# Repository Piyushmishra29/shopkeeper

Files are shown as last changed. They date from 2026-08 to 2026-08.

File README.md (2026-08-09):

<p align="center">
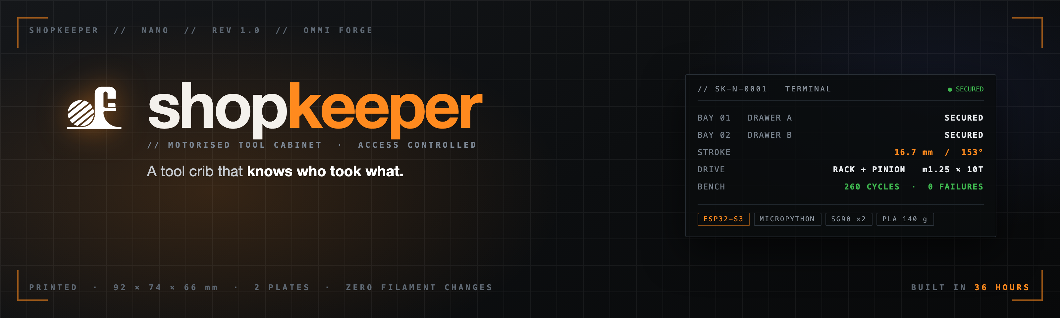
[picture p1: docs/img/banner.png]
shopkeeper NANO — a motorised tool cabinet
  
</p>

<p align="center">
  
  
  
  
</p>

<p align="center">
  
  
  
  
</p>

**A tool crib that knows who took what.**

Type a PIN on your phone and the one drawer you are cleared for slides itself open. Take what you
need, push it shut, and the pick is logged against your name. Try the other drawer and nothing
moves.

Built as a working demonstrator to pitch against the industrial smart tool cabinets that land in
India around **₹20 lakh**. Same job, out of about 140 g of filament and roughly ₹2,000 of parts.

<p align="center">
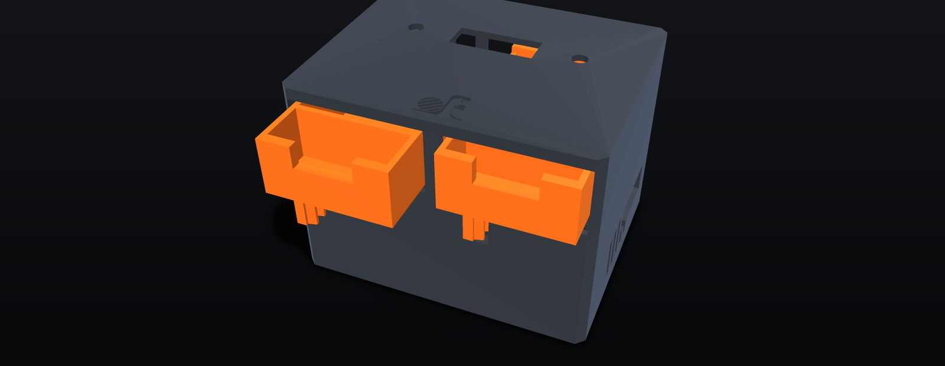
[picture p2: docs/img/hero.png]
shopkeeper NANO, one drawer driven open
  
</p>

<table>
<tr>
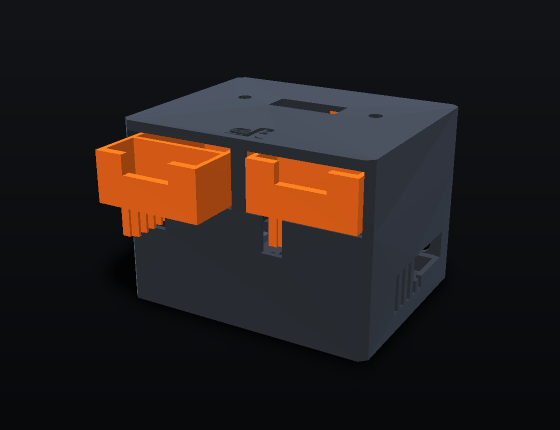
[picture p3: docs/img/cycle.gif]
a drawer opening and closing
<td width="50%"></td>
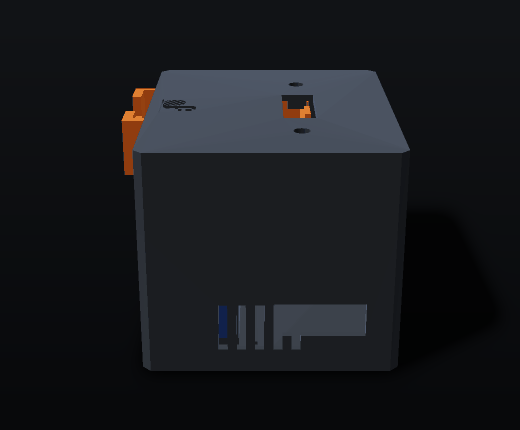
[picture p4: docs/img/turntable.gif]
turntable
<td width="50%"></td>
</tr>
<tr>
<td align="center"><em>16.69 mm of travel, commanded</em></td>
<td align="center"><em>92 × 74 × 66 mm, 140 g of filament</em></td>
</tr>
</table>

> Every image and animation in this README is rendered from the shipped meshes by
> [`tools/make_assets.py`](tools/make_assets.py), through a numpy software rasteriser
> ([`tools/render.py`](tools/render.py)) written for the job because there is no GPU here. The
> mechanism animation turns the pinion by θ and slides the drawer by `R_P·θ` — the same relation
> the firmware commands. Nothing is drawn by hand, so if the geometry is wrong the picture is wrong.

| | |
|---|---|
| **Machine** | shopkeeper **NANO**, 92 × 74 × 66 mm |
| **Geometry** | frozen — `nano/*.stl` is what goes on the plate |
| **Firmware** | 1.0.0, running on the board |
| **Print** | 2 plates, 140 g solid (~119 g sliced) |
| **Bench** | 60/60 open-close cycles on bay two, no failures, no brownout |
| **Spec** | [`docs/superpowers/specs/2026-08-08-toolcell-design.md`](docs/superpowers/specs/2026-08-08-toolcell-design.md) |
| **Lineage** | [`docs/history.md`](docs/history.md) — four superseded generations and what killed each |

---

## Why it exists

A machine shop bleeds tooling. Not dramatically — a carbide end mill walks off, nobody
remembers who had it last, and the shop buys another. Nobody is stealing; nobody is keeping
a record either. Multiply by a year and it is a real number, and it never appears on any
report because there is nothing generating one.

The fix is not measurement. You do not need to weigh, photograph or tag anything to change
behaviour — you need a drawer that stays shut until somebody is cleared to open it, and a
line in a log with their name on it. **Nobody walks off with a tool their name is attached
to.** The deterrent is the record.

So this is exactly that, and nothing beyond it: controlled access plus an append-only log,
on top of a tool database. **It counts nothing, and the interface says so** rather than
implying a measurement it never takes. There is no load cell, no camera, no RFID, and the
page does not pretend otherwise.

Built in 36 hours out of 140 g of filament and about ₹2,000 of parts, so the argument can be
made with a working machine on the table instead of a slide.

---

---

## The machine that exists

<p align="center">
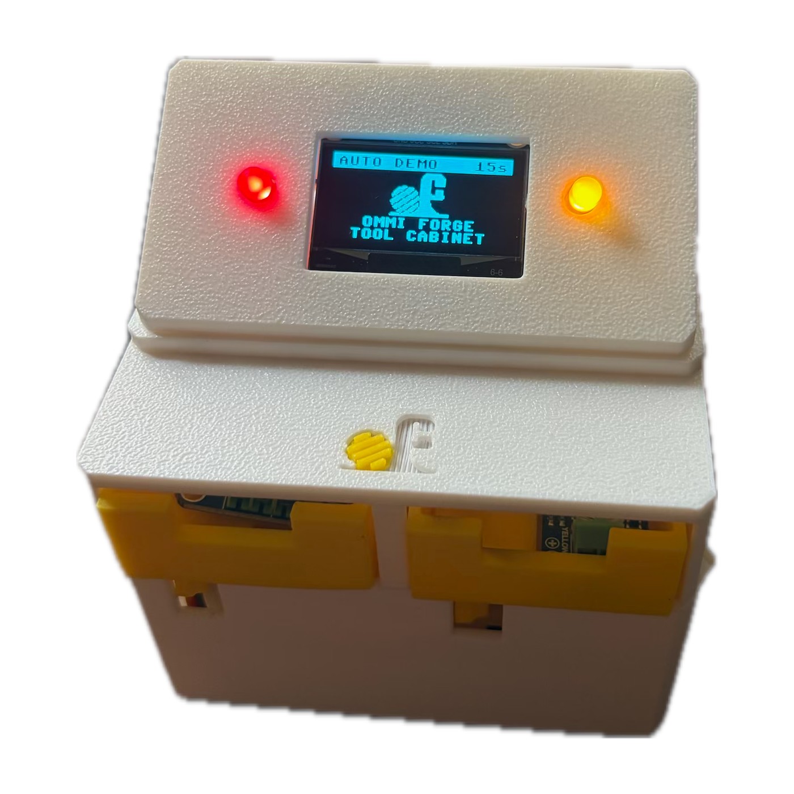
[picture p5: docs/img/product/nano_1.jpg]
shopkeeper NANO, assembled and running
  
</p>

<table>
<tr>
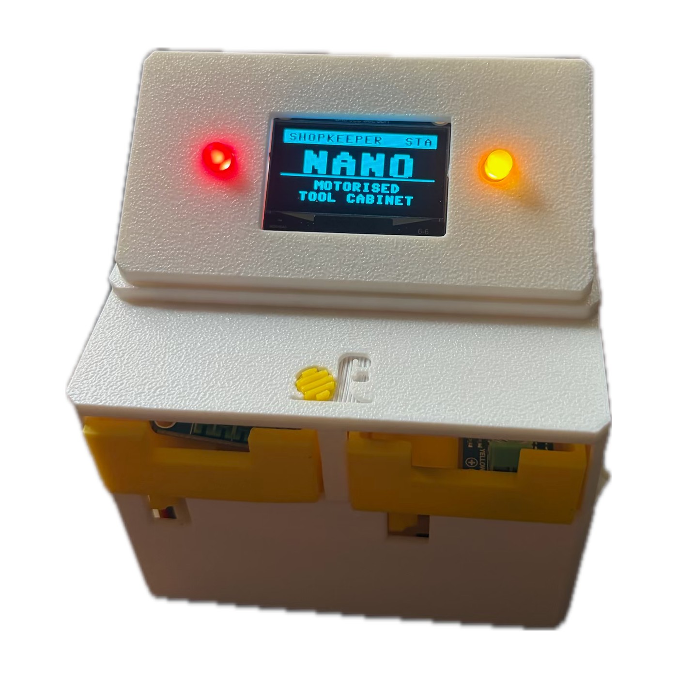
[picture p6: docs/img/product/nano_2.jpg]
shopkeeper NANO
<td width="33%"></td>
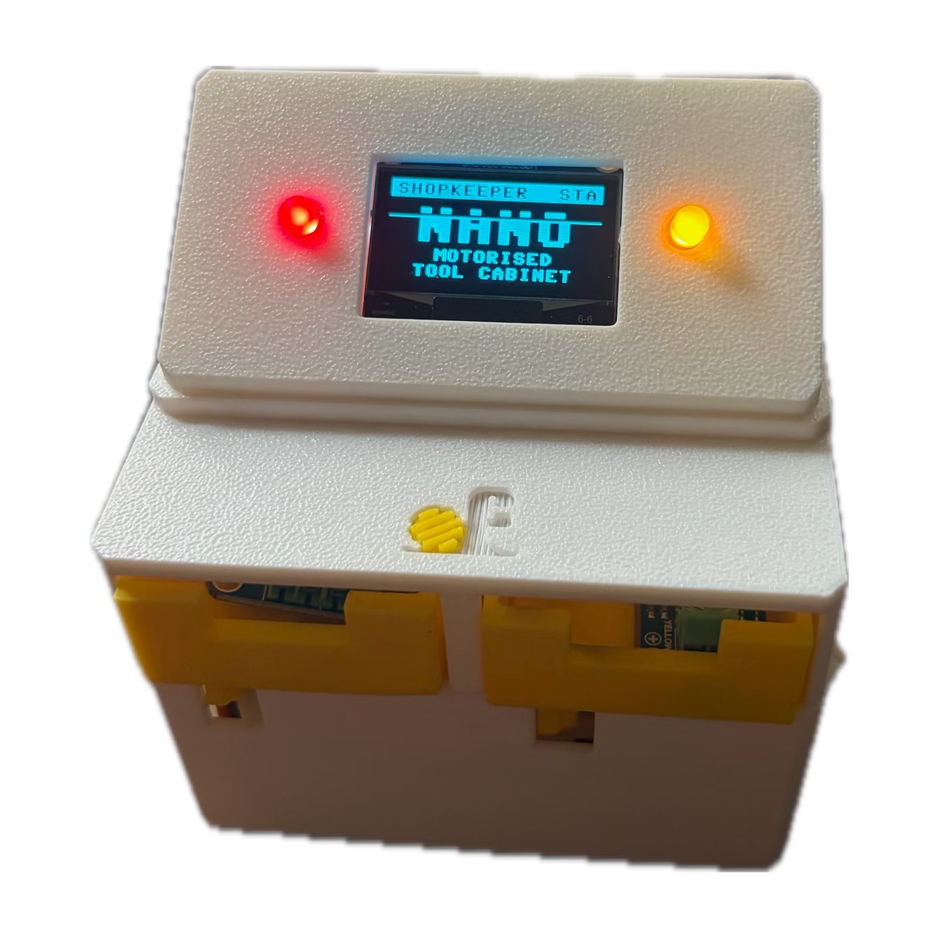
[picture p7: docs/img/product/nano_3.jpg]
shopkeeper NANO
<td width="33%"></td>
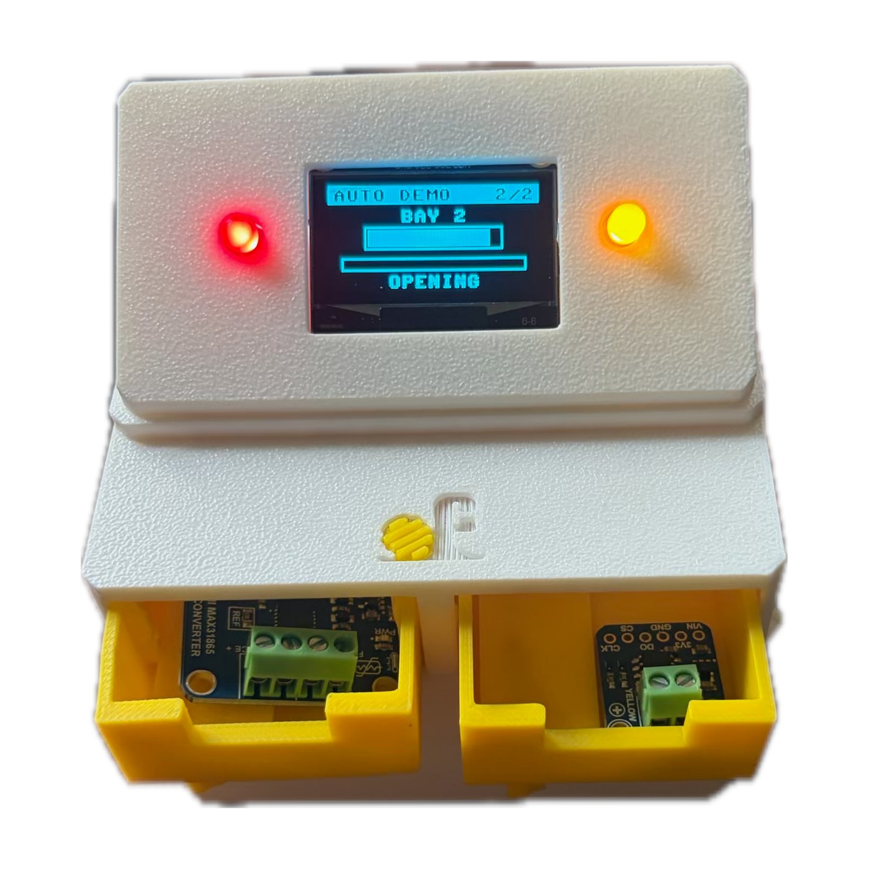
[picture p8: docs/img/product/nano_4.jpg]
shopkeeper NANO
<td width="33%"></td>
</tr>
</table>

Not a render — the printed article, powered up, mid attract-loop. The panel is
showing the scripted demo counting down; the two lamps are the bay indicators;
the mark on the lid is a separate part pressed into a debossed pocket, printed
in the same 0.4 nozzle as everything else.

Everything on this page is measured from that object or from the meshes that
produced it. **260 open-close cycles, zero failures**, both bays driven
simultaneously.

Photographs were cut from their background with `tools/cutout.swift`, which
uses Vision's foreground-instance mask — the same engine behind Preview's
Remove Background. The obvious route was `rembg`, which cannot be installed
here: `onnxruntime` has no build for Python 3.14.

---

---

## Bench results

| run | result |
|---|---|
| bay 2, sequential | 60 / 60 |
| bay 1, **concurrent** | 100 / 100 |
| bay 2, **concurrent** | 100 / 100 |
| **total** | **260 cycles · 0 failures · 0 reboots** |

The last two runs drove **both bays at once** — two servos under load on one rail, which is the
worst case for supply sag. Nothing reset.

A cycle only counts if the harness polled until the drawer stopped moving **and** its own open
flag had flipped. The API returns `202` on acceptance, so counting requests would have proved
nothing. Harness and raw reports: [`tools/bay2_endurance.py`](tools/bay2_endurance.py).

## How it works

```mermaid
flowchart LR
  P["Phone or laptop<br/>any browser"] -->|"HTTP · PIN"| E
  subgraph CAB["shopkeeper NANO"]
    E["ESP32-S3<br/>MicroPython 1.28"]
    E -->|"PWM 650–2350 µs"| S1["SG90 · GPIO 5"]
    E -->|"PWM 650–2350 µs"| S2["SG90 · GPIO 6"]
    E -->|"I²C · GPIO 1/2"| D["SH1106 OLED<br/>top face"]
    E -->|"append-only"| L[("Log<br/>/data on flash")]
    S1 --> R1["pinion m1.25 × 10T"] --> B1["Bay 1 drawer<br/>16.7 mm"]
    S2 --> R2["pinion m1.25 × 10T"] --> B2["Bay 2 drawer<br/>16.7 mm"]
  end
```

Everything is on the board. No cloud, no broker, no account — the cabinet raises its own
access point, so it works in a meeting room with no wifi and keeps working when the internet
does not.

The log is written **before** the confirmation goes back, so a move that happened is always
recorded even if the network drops mid-reply. The record is the product; it does not get to be
best-effort.

Sequence and state diagrams are in [`docs/BUILD.md`](docs/BUILD.md).

## Geometry for a client or a machine shop

Every part, in three formats. **The mesh is the same object in all of them** — one generator,
one export.

### → [**`MODELS/`**](MODELS/) ← everything is in here

| folder | format | for |
|---|---|---|
| [**`MODELS/STL/`**](MODELS/STL) | STL | printing, and 3D CAM — **start here** |
| [`MODELS/OBJ/`](MODELS/OBJ) | OBJ | import into almost anything |
| [`MODELS/PLATES-3MF/`](MODELS/PLATES-3MF) | 3MF | slicer-ready plates, orientation baked in |
| [`MODELS/DXF/`](MODELS/DXF) | DXF, mm | flat profiles for laser, waterjet or 2D cut |

[`MODELS/README.md`](MODELS/README.md) lists every part with its size and what it does.

<p align="center">
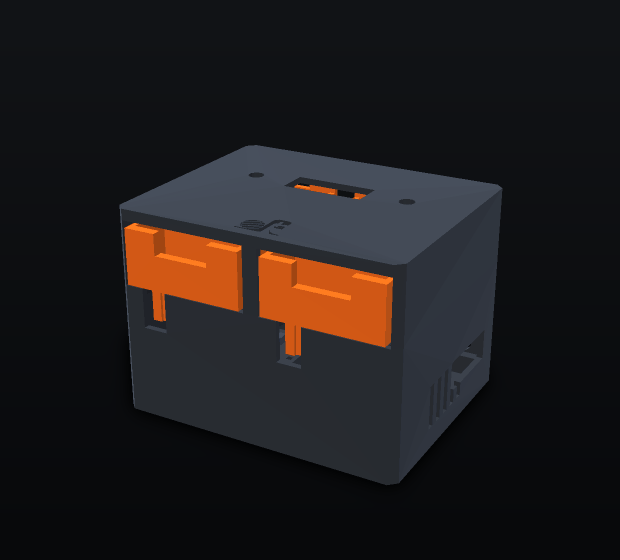
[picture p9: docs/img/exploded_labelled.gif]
exploded, each part named
  
</p>

**There is no STEP file, and it is worth saying why.** STEP is a boundary representation —
exact surfaces, true arcs, named faces. This geometry is a triangle mesh, authored for a
printer. Converting mesh to STEP does not recover what was never in it: you get a solid built
from thousands of facets, which imports and looks correct and is unpleasant to machine, because
every cylinder is really a polygon and the toolpath chatters around it.

If the shop wants proper B-rep, the honest route is to rebuild from `cad/nano.py` — every
dimension is a named entry in the `P` dict at the top of that file, and each part function
reads as a recipe. It is half a day for a CAD operator and the result is genuinely machinable.
Importing the STL into Fusion or FreeCAD and converting to solid is the fast, faceted
alternative and is fine for a one-off.

Regenerate the exports at any time:

```sh
.venv/bin/python cad/export_cam.py     # rebuilds MODELS/ entirely
```

---

---

## Scaling it

Two drawers is the demonstrator. Nothing about the approach is limited to two, and the reason
is the same rule that makes it secure: **only one drawer is ever open.** That single constraint
is what keeps a hundred-drawer wall cheap to power and simple to reason about.

| | drawers | actuation | power | what changes |
|---|---|---|---|---|
| **demonstrator** | 2 | 2 × SG90 direct from the board | USB power bank | — |
| **one cabinet** | 16 | 1 × PCA9685, 16 channels over I²C | 5 V 3 A | one driver board, same firmware loop |
| **a bay of cabinets** | 100+ | 7 × PCA9685 on one I²C bus | 5 V 5 A | addressing, not architecture |
| **a shop** | 32 cabinets | one controller each | local | a server that aggregates the logs |

### Why the power does not scale with the drawers

An SG90 pulls about 700 mA while it moves and nothing at all when it is detached — the firmware
already cuts the signal once a move settles. Because access control means **one drawer at a
time**, the worst case is one servo moving plus a hundred sitting idle, not a hundred moving.
A hundred-drawer wall draws about what this two-drawer box does.

That is not a lucky coincidence. The security model and the power budget are the same
constraint viewed twice.

### What actually gets harder

The mechanism scales by repetition. The hard parts are elsewhere, and they are all software:

- **Identity.** A 4-digit PIN does not survive fifty operators. It becomes an RFID badge or a
  phone, and the log has to carry a person rather than a session.
- **The database.** One cabinet can keep its log in flash. Thirty-two cabinets need a server,
  and the cabinets need to keep working when it is unreachable — local log, sync on reconnect.
- **Integration.** A shop wants tool consumption against a job number and a cost centre, which
  means talking to whatever ERP already exists.
- **Actuation, for real drawers.** An SG90 moves a 20 g printed bin. A drawer rated for 80 kg
  of tooling wants a proper geared motor or a solenoid latch and a gas strut. The rack and
  pinion stays; the motor changes.

**None of that is a hardware problem, and that is the point.** The cabinet is the cheap half.
What a shop is buying is controlled access and a record — and that is where both the difficulty
and the value sit.

---

## What it deliberately isn't

**It does not count anything.** Stock decrements because the software said you would take two.
Worth repeating, because it is the crux of the pitch rather than an apology: the ₹20 lakh cabinets
work the same way. Their inventory is trust-based, with no sensors anywhere in the product. The moat is access
control and the database, not sen## Geometry

### → [**`MODELS/`**](MODELS/) ←

| folder | for |
|---|---|
| [**`MODELS/STL/`**](MODELS/STL) | printing and 3D CAM — **start here** |
| [`MODELS/OBJ/`](MODELS/OBJ) | import into almost anything |
| [`MODELS/PLATES-3MF/`](MODELS/PLATES-3MF) | slicer-ready plates, orientation set |
| [`MODELS/DXF/`](MODELS/DXF) | flat profiles, mm, for laser or waterjet |

<p align="center">
  exploded, each part named
</p>

No STEP: this is a triangle mesh authored for a printer, and converting mesh to B-rep does not
recover surfaces that were never there. For real B-rep, rebuild from the `P` dict in
[`cad/nano.py`](cad/nano.py) — every dimension is one named number.
[`MODELS/README.md`](MODELS/README.md) lists every part and its size.

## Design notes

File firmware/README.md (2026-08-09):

# shopkeeper NANO — firmware

MicroPython for the ESP32-S3. Brings up its own wifi, serves a control UI, and
drives the two drawer servos.

Tested on the board in hand: **ESP32-S3, MicroPython 1.28.0**, 2.0 MB free heap.

## What it does, and why that

The industrial smart tool cabinets this is pitched against — the ~₹20 lakh ones — do
not sense anything. No load cells, no cameras, no RFID. Inventory is
trust-based. What a machine shop is actually buying is **a locked drawer and a
record of who opened it**, so that is exactly what this implements:

- a PIN gate that re-locks itself after two minutes idle
- every open, close, unlock and rejected PIN written to an append-only log
- a per-drawer tool register

Nothing here claims to know whether a tool is physically present, and the UI
says so rather than implying a measurement it never takes.

## Layout

```
config.py   everything a unit differs on: wifi, pins, PIN, endpoints, tools
servo.py    SG90 driver — eased moves, calibrated endpoints, auto-detach
store.py    calibration + log persistence, with flash-wear rate limiting
server.py   asyncio HTTP server and the JSON API
main.py     boot: network, restore calibration, park closed, serve
www/        the UI, served straight off flash
```

## Flashing

```sh
PORT=/dev/cu.usbmodem5A790574951          # yours may differ; ls /dev/cu.*
mpremote connect $PORT mkdir :www
for f in config.py servo.py store.py server.py main.py; do
  mpremote connect $PORT cp $f :$f
done
mpremote connect $PORT cp www/index.html :www/index.html
mpremote connect $PORT reset
```

`main.py` runs automatically on power-up. To watch it boot:
`mpremote connect $PORT repl` then Ctrl-D.

## Using it

The cabinet brings up its own access point, because a demonstrator has to work
in a meeting room with no guest wifi:

| | |
|---|---|
| SSID | `shopkeeper-NANO` |
| Password | `forge2026` |
| URL | **http://192.168.4.1/** |
| PIN | `2468` |

Set `JOIN = ("ssid", "password")` in `config.py` to join an existing network
first and fall back to the AP.

## Wiring

| | |
|---|---|
| Drawer A servo signal | GPIO 5 |
| Drawer B servo signal | GPIO 6 |
| Servo V+ | **5 V, not the 3V3 rail** |
| Servo GND | common with the ESP32 GND |

Two SG90s stalling together pull well over an amp. Power them from the 5 V pin
or a separate supply — a USB port feeding the 3V3 regulator will brown the
board out mid-move and you will spend an afternoon blaming the code.

## Calibration

The endpoints in `config.py` are conservative on purpose:

```
span_us / 2000 * 180 = degrees      degrees / 180 * 31.42 = mm of drawer
650..2350  ->  1700 us  ->  153 deg  ->  26.7 mm of the 31.4 available
```

The mechanism can do 31.4 mm at a full 180°, but most SG90 clones stall against
their own end stop somewhere past 160° and cook themselves holding there. The
UI's **Calibrate** panel jogs each servo live while you watch the real drawer,
and writes the endpoints to `/data/cal.json` on release.

Set them by eye against the printed part, not from this table.

## API

| Method | Path | |
|---|---|---|
| GET | `/api/state` | everything: lock state, drawers, tools, log |
| POST | `/api/unlock` | `{"pin":"2468"}` |
| POST | `/api/lock` | |
| POST | `/api/drawer` | `{"id":0,"open":true}` → 202, move runs async |
| POST | `/api/cal` | `{"id":0,"open_us":2350}` or `{"id":0,"jog_us":1500}` |
| DELETE | `/api/log` | |

Everything except `/api/state`, `/api/unlock` and `/api/lock` returns **403**
while the cabinet is locked.

## Notes for the next person

Two MicroPython differences bit during the build, both of which fail at *import*
time rather than where you'd look:

- `{**a, "b": 1}` — dict unpacking inside a display is a `SyntaxError`
- `str.ljust` does not exist

The servo is deliberately de-energised 450 ms after each move. A hobby servo
holds position by hunting, so it buzzes and warms up indefinitely otherwise,
and the rack and pinion is not backdriveable enough for a drawer to creep.

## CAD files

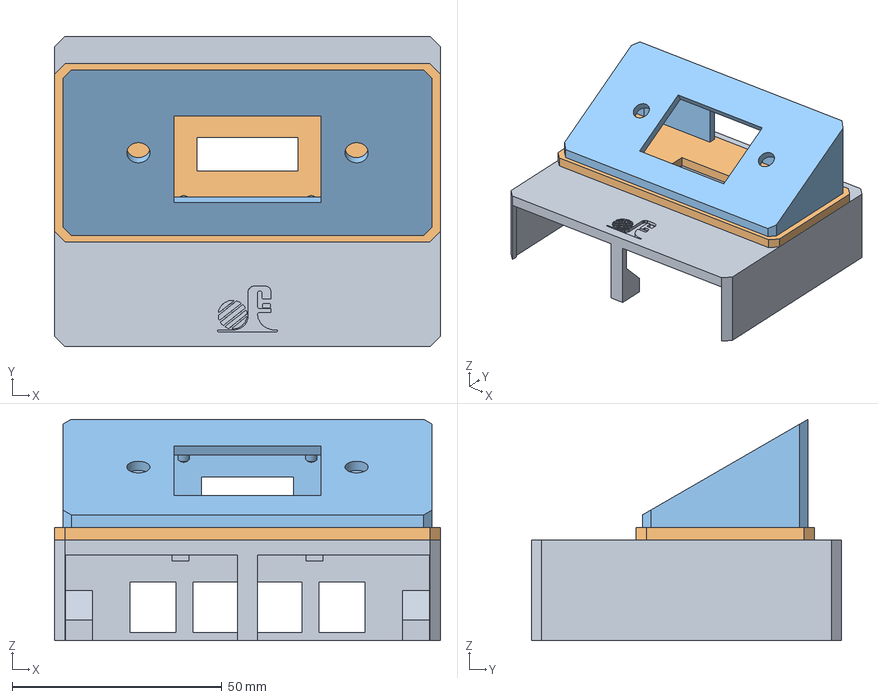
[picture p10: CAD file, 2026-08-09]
nano/mount/assembly_mount.3mf
92.0 x 74.0 x 52.8 mm
case_upper
mount_base
mount_body

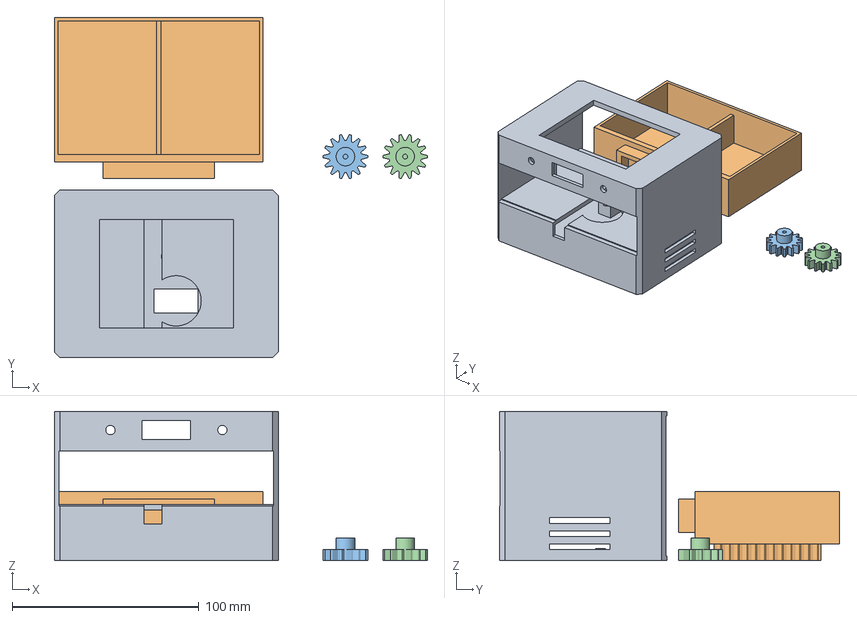
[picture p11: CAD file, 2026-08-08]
mini/plates/plate_mini.3mf
200.0 x 182.5 x 80.0 mm
case
drawer
pinion
pinion_spare

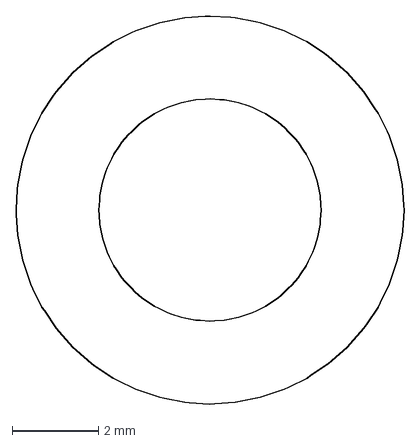
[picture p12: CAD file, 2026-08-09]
MODELS/DXF/pinion_z3.00.dxf
9.00 x 9.00 mm

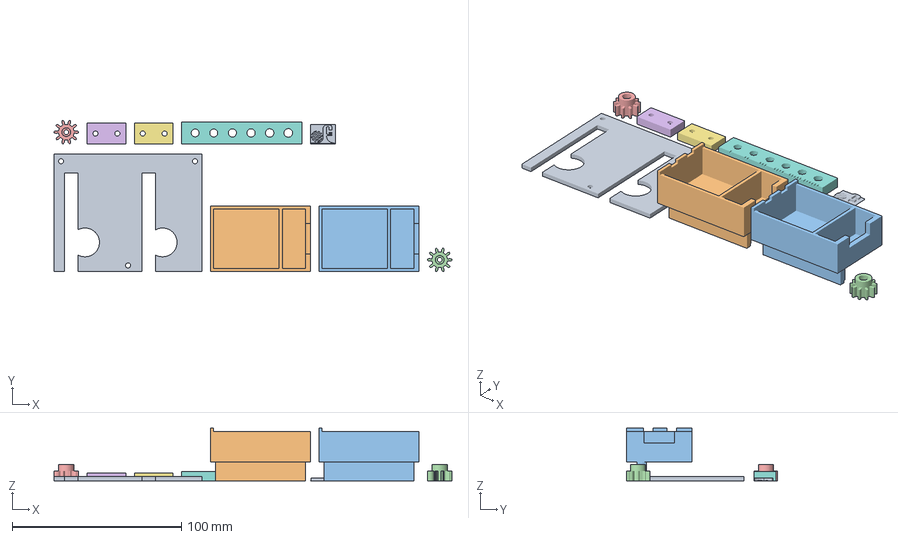
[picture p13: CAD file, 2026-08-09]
MODELS/PLATES-3MF/plate_2_mechanism.3mf
234.9 x 89.4 x 31.2 mm
deck
drawer_A
drawer_B
pinion_A
pinion_B
servo_shim_A
servo_shim_B
spline_gauge
logo_inlay

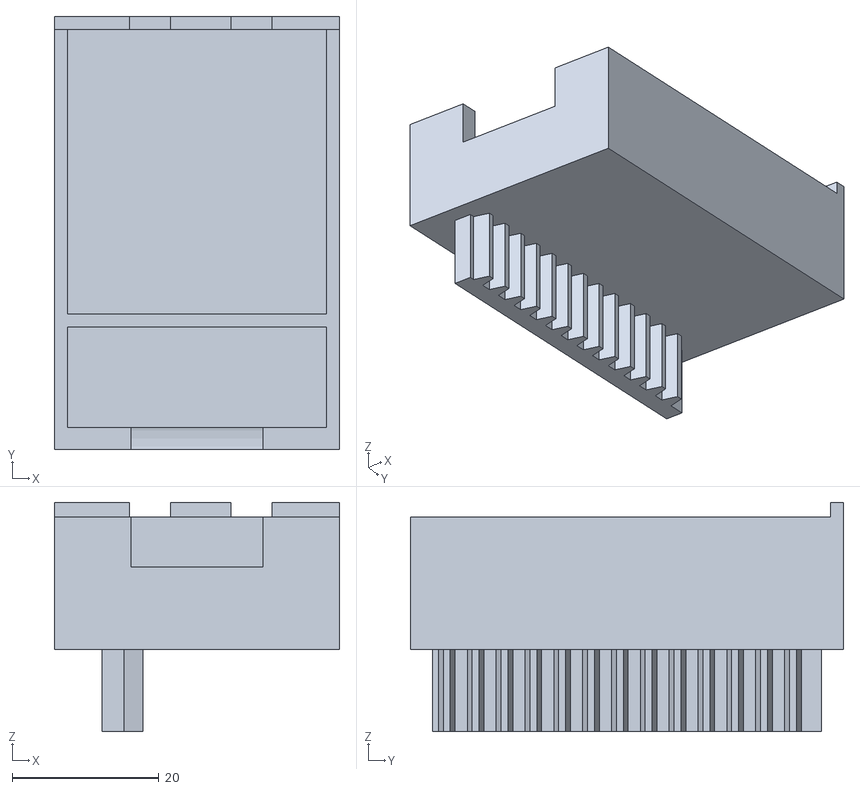
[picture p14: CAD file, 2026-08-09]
MODELS/STL/drawer.stl
38.8 x 59.0 x 31.2

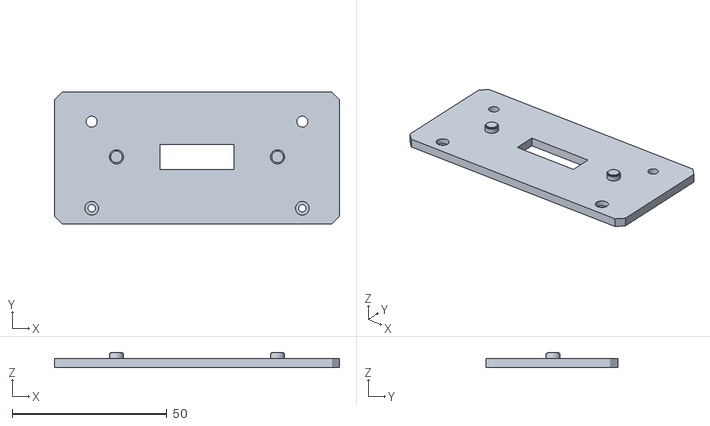
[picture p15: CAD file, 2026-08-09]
nano/mount/printpose/mount_base.stl
92.0 x 42.5 x 5.00

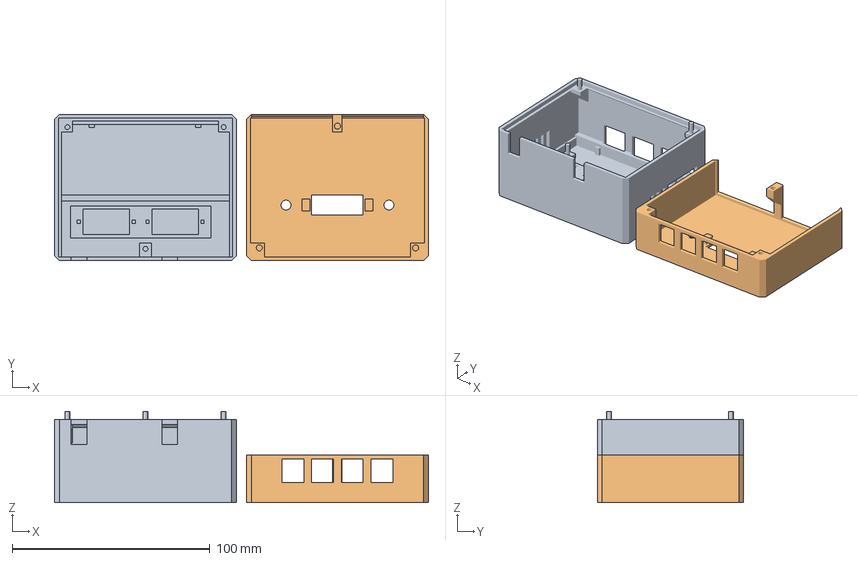
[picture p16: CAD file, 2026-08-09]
nano/plates/plate_1_case.3mf
189.0 x 74.0 x 46.0 mm
case_lower
case_upper

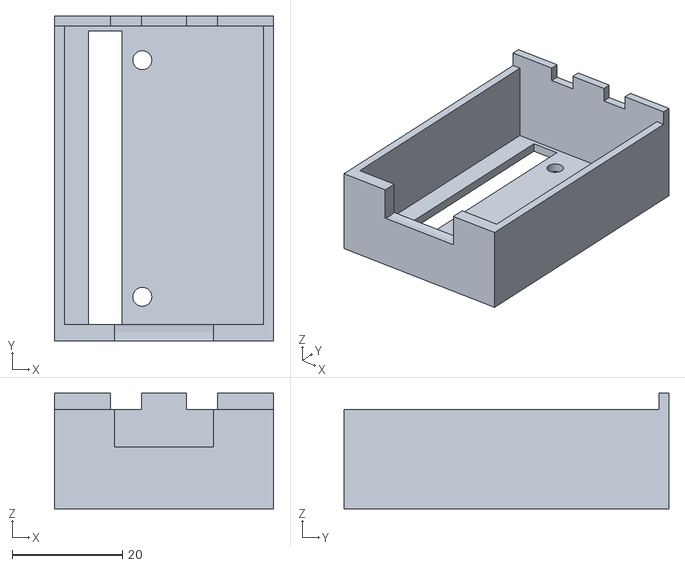
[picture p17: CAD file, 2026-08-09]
nano/prev/drawer_single.stl
39.8 x 59.0 x 21.0

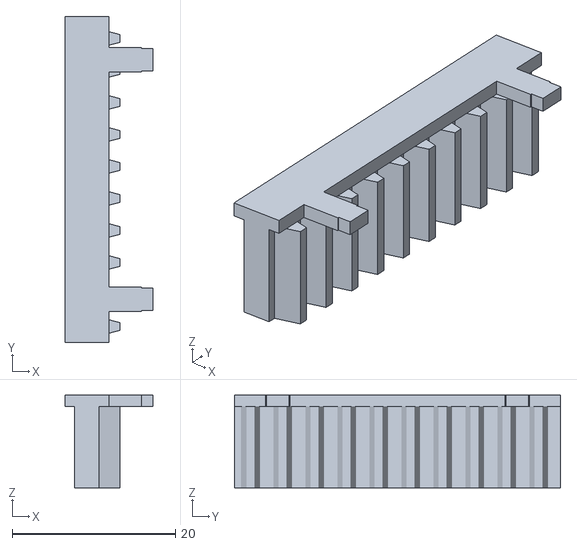
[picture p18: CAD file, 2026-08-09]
nano/simple/rack.stl
10.8 x 40.0 x 11.4

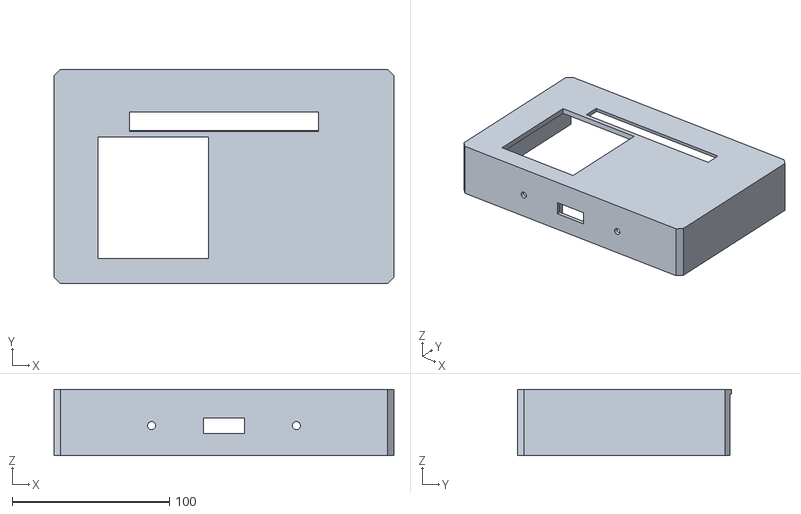
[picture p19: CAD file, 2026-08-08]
out/case_head.stl
216.0 x 136.0 x 42.0

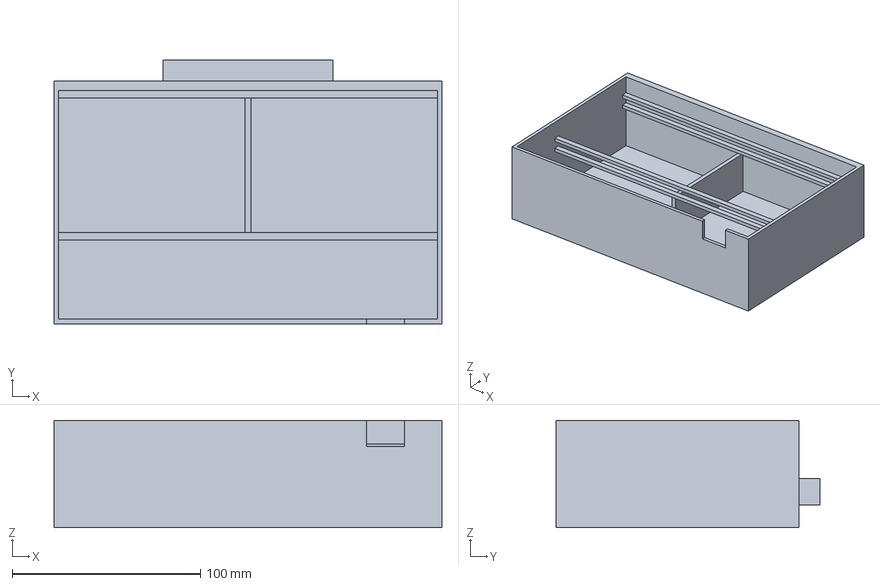
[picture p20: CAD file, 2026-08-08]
out/plates/plate_4_drawer.3mf
206.0 x 140.0 x 57.0 mm

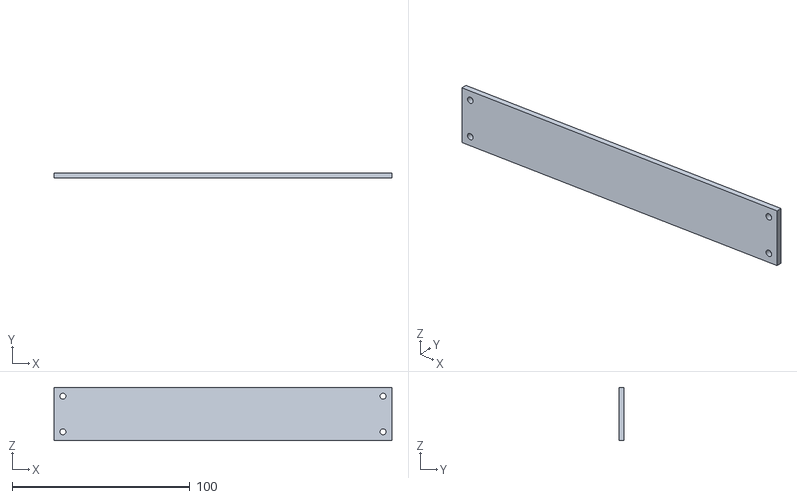
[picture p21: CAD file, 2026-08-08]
out2/elec_panel.stl
190.0 x 3.00 x 30.0

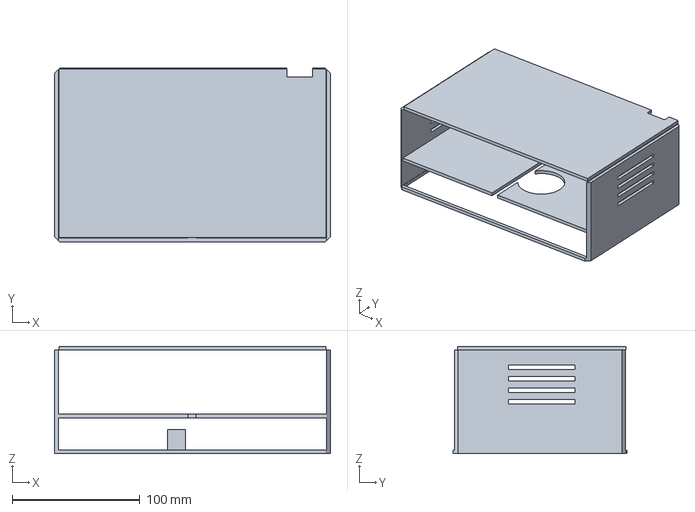
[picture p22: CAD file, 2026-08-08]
out2/plates/plate_1_bay_A.3mf
216.0 x 136.0 x 84.0 mm

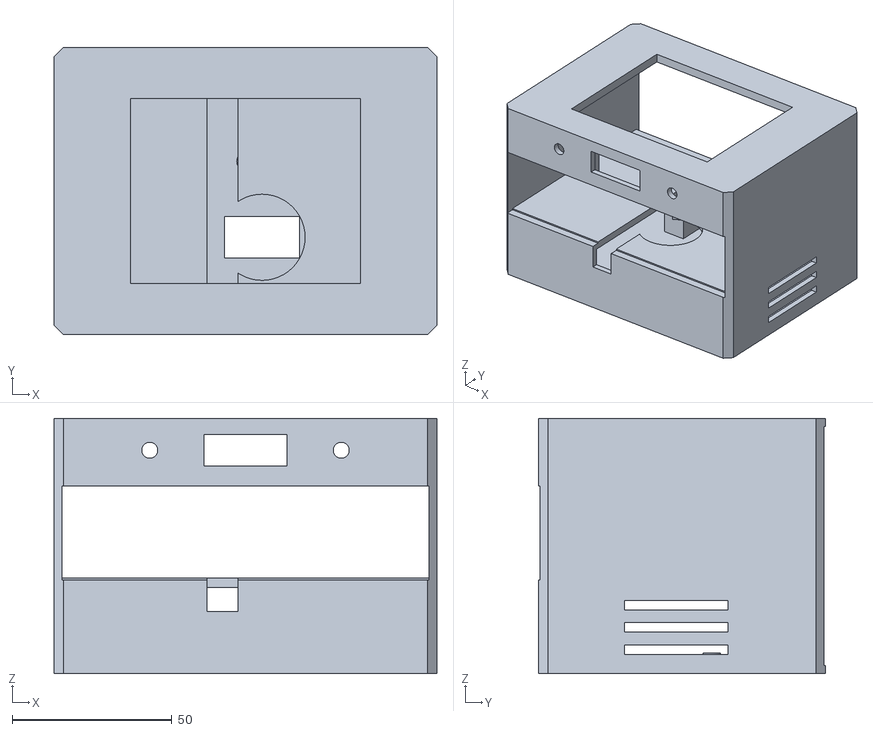
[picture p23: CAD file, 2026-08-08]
mini/case.stl
120.0 x 90.0 x 80.0

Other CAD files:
MODELS/DXF/drawer_z9.00.dxf
MODELS/PLATES-3MF/plate_ALL.3mf
MODELS/STL/deck.stl
nano/mount/mount_base.stl
MODELS/DXF/case_lower_z0.70.dxf
MODELS/DXF/case_upper_z0.70.dxf
MODELS/DXF/deck_z1.25.dxf
MODELS/PLATES-3MF/plate_0_gears.3mf
MODELS/PLATES-3MF/plate_1_case.3mf
MODELS/STL/case_lower.stl
MODELS/STL/case_upper.stl
MODELS/STL/knob.stl
MODELS/STL/logo_inlay.stl
MODELS/STL/pinion.stl
MODELS/STL/rack.stl
MODELS/STL/servo_shim.stl
MODELS/STL/spline_gauge.stl
cad/export/case_lower_z0.70.dxf
cad/export/case_upper_z0.70.dxf
cad/export/deck_z1.25.dxf
cad/export/drawer_z9.00.dxf
cad/export/pinion_z3.00.dxf
mini/drawer.stl
mini/pinion.stl
nano/mount/gauge_screen.stl
nano/mount/gauge_spigot.stl
nano/mount/mount_body.stl
nano/mount/plate_gauges.3mf
nano/mount/plate_mount.3mf
nano/mount/printpose/gauge_screen.stl
nano/mount/printpose/gauge_spigot.stl
nano/mount/printpose/mount_body.stl
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

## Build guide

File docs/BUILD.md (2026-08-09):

# Building shopkeeper NANO

Everything needed to print it, flash it, wire it and check it. The pitch lives in
[the README](../README.md); this is the manual.

---

## The argument

The established smart tool cabinets land in India at roughly ₹20 lakh. They are serious machines:
800 × 790 mm on the floor, drawers rated 80 kg, up to 48 compartments per drawer, nine cabinets
daisy-chained per controller, three lock tiers rising to a per-compartment electronic flap.

The finding that shapes this whole project is this:

> **They sense nothing.** No load cells, no cameras, no RFID on the tools. Inventory is
> trust-based. The system knows stock because it locked everything except the one box it told you
> to open, and then assumed you took the quantity on the screen. There is a manual *stock
> adjustment* function precisely because reality drifts.

So the moat is not sensing. It is **mechanical access control plus a record of who opened what**,
sitting on top of a good tool database. The cabinet is the cheap half; the software stack — central
tool database, cost centres and user groups, shopfloor pick client — is what commands the price.

That is why a ₹2,000 machine can stand in a room next to a ₹20 lakh one and make an argument. It
does the mechanically honest part — a drawer that is locked until you are cleared, and a log that
says who opened it — and it claims nothing beyond that. **It does not count anything**, and the UI
says so rather than implying a measurement it never takes.

These systems are priced for European tier-1 automotive suppliers. Most Indian job shops will never
buy at ₹20 lakh. A system doing 80% of the job at ₹4–5 lakh addresses a real, unserved market, and this is
the door-opener that gets you into the room to talk about it.

---

---

## The machine

Two drawers **side by side**, not stacked, so one mechanism deck serves both. Stacking would have
doubled the height, because a vertical SG90 costs 26 mm of dead space under every deck.

```
    z 66  ┌──────────────────────────────┐
          │  top face: OLED window,      │   case_upper, 24 mm
          │  2× LED holes, debossed mark │   prints top-face-down
    z 42  ├──────────────────────────────┤
          │  bay: 2 drawers, 18 mm deep  │   deck at z 39.5 .. 42
    z 39  ├──────────────────────────────┤
          │  mech bay: 2× SG90 shaft-up, │   case_lower, open top,
          │  2 pinions, ESP32-S3 + board │   prints floor-down
    z  0  └──────────────────────────────┘
                    92 × 74 mm
```

| | |
|---|---|
| Case | 92 × 74 × 66 mm |
| Drawer, each | 39.8 × 59 × 18 mm body (+3 mm anti-tip rib), **36.0 × 54.0 × 16.2 mm** of bin |
| Deck | 2.5 mm, top face at z 42 |
| Gearing | module **1.25**, **10 teeth**, 14.5° pressure angle, 6 mm face |
| Pitch radius | **6.25 mm** |
| Full travel | **19.63 mm** = π × 6.25 = one **half turn** of the pinion |
| Travel as shipped | **16.69 mm** — the firmware commands 650–2350 µs = 1700 µs = 153° |
| Reserve | **2.94 mm** the mechanism can do that the firmware never asks for |
| Still on the deck | 39.4 mm of a 59 mm drawer at *full* travel |
| Mass | 140 g solid over 2 plates, ~119 g sliced |

### Why 16.69 and not 19.63

An SG90 nominally spans 500–2500 µs for 180°, but clones stall against their own end stop somewhere
past 160° and cook themselves holding there. So the shipped endpoints deliberately ask for less
than the mechanism can do:

```
span_us / 2000 × 180 = degrees          degrees / 180 × 19.63 = mm of drawer
650 .. 2350  →  1700 µs  →  153°  →  16.69 mm of the 19.63 available
```

16.69 mm opens 28% of a 59 mm drawer, which is enough to reach the front row. The remaining 2.94 mm is
headroom, not a shortfall — and the **Calibrate** panel in the UI jogs each servo live while you
watch the real drawer, then writes the endpoints to `/data/cal.json`. Set them by eye against the
printed part, not from this table.

### How it drives

<p align="center">
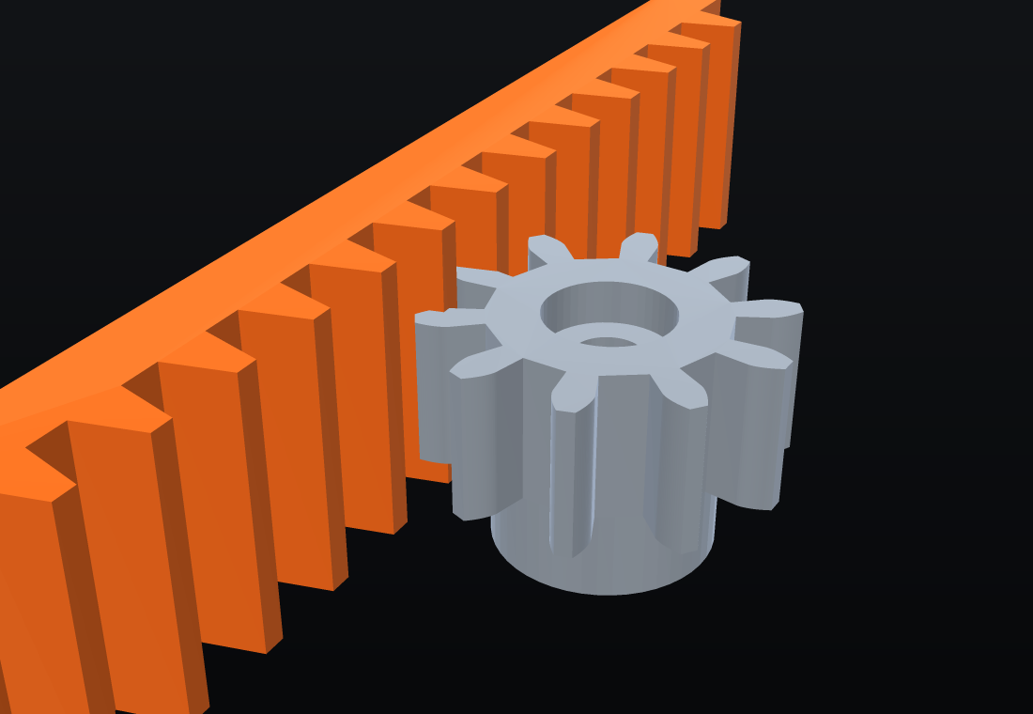
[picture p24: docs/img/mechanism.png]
the pinion meshing with the drawer's integral rack
  
</p>

<p align="center">
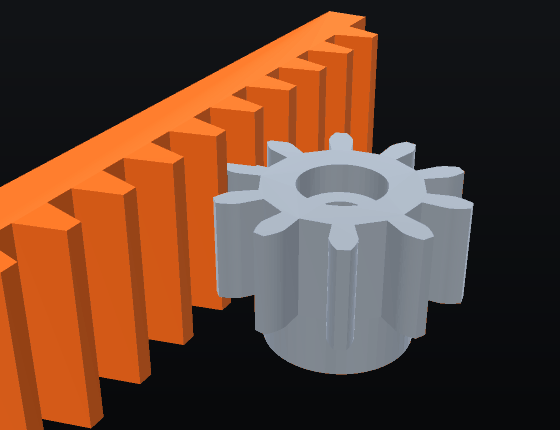
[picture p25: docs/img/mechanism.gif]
the pinion turning and driving the rack
  
</p>

A rack and pinion, and the rack is **not a separate part** — the teeth are moulded into a blade
that hangs off the drawer's own underside. One piece, nothing to peg in, nothing to come loose.
The drawer body is left out of these two pictures because it sits directly over the mesh and hides
it completely.

The gear lies flat on a vertical servo shaft, like a turntable, so its teeth face **sideways**. That
single fact decides the whole layout: a rack cut into a drawer floor would present its teeth
downward at a gear that never looks that way, and could not have driven anything. The teeth have to
be on a vertical face, which is why the blade hangs below rather than lying flat.

### The two details that were nearly fatal

**Stub teeth.** A full-depth involute at m1.25 comes to a 0.45 mm tip — under one extrusion width,
so the machine rounds it off and the contact it was supposed to make never happens. The addendum is
0.8 module instead of 1.0, which puts the tip at 0.75 mm and still leaves a contact ratio of 1.8.

**The SG90's output shaft is not centred on its body.** It sits ~5.9 mm from one end, which is
plain to see on the part and was modelled nowhere. The servo pocket was centred on the pinion axis,
so the servo either would not go in at all or would put its shaft 5.5 mm off the axis — a
centre-distance error half as big as the pitch radius. The gear pair could never have meshed.

---

---

## Every part

<p align="center">
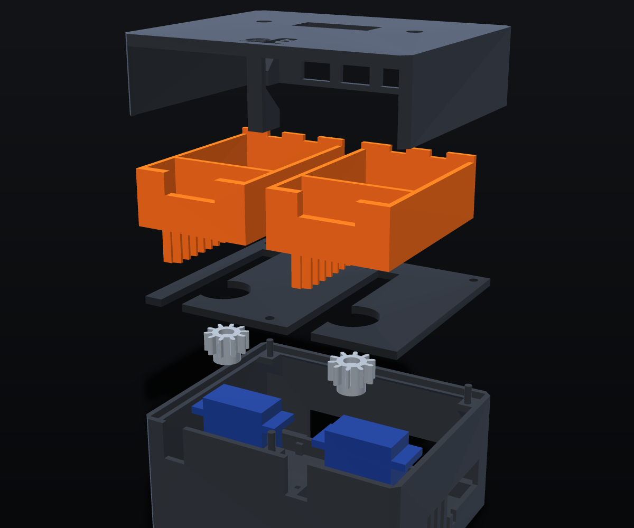
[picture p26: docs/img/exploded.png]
exploded view of every part
  
</p>

<p align="center">
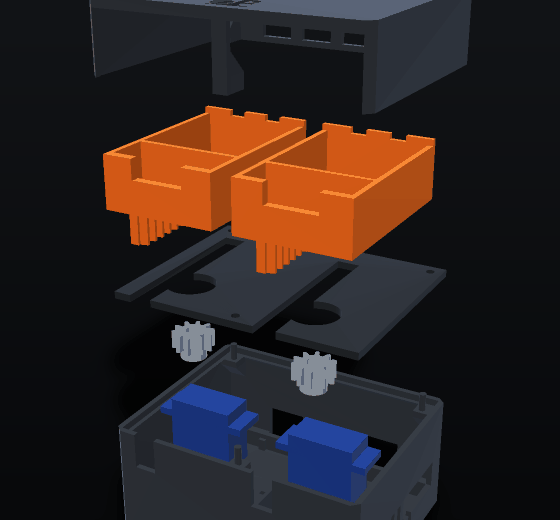
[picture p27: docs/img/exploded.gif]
the cabinet coming apart
  
</p>

Top to bottom: the lid, two drawers each carrying its own toothed blade, the deck the drawers ride
on with a bore for each gear, the two pinions, the two SG90s in their wells, and the base with the
ESP32 bay behind them.

---

---

## Print it

The meshes in `nano/` are the build. You do not have to run any Python to print.

| Plate | File | Objects | Mass | Colour |
|---|---|---|---|---|
| 1 — case | `nano/plates/plate_1_case.3mf` | `case_lower`, `case_upper` | **89.3 g** | white |
| 2 — mechanism | `nano/plates/plate_2_mechanism.3mf` | `deck`, 2× `drawer`, 2× `pinion`, 2× `servo_shim`, `spline_gauge`, `logo_inlay` | **60.0 g** | yellow |

One colour per plate, so a single-nozzle machine makes **zero filament changes** — swap the spool
between the two prints. Both plates fit a 256 mm bed. A plain `.stl` sits beside each `.3mf`: an
STL carries no filament or extruder data at all, so a slicer cannot stop and ask you to map
materials.

`nano/plates/plate_ALL.3mf` puts everything on one colour-coded plate. That one is for **looking
at**, not for printing — it declares materials, so a slicer will stop and ask you to map filaments.

Nine STLs are generated; eight of them are on the plates. `knob.stl` is the alternative to the
scalloped finger pull moulded into the drawer front, and is only printed if you set `P["pull"] =
"knob"` and regenerate.

**Print orientation is already baked into the plates.** `case_upper` is flipped and printed
top-face-down: the debossed mark's edges then form against the bed, which is the crispest surface
the machine makes. `pinion` prints gear-face-down with the horn pocket up.

### Assembly order

1. Screw each SG90 down onto its **`servo_shim`** — a 1.6 g part whose only job is to set the
   servo height. That height sets the horn height, which sets the pinion height, which decides
   whether the gears engage at all. If your servo measures differently, reprint the 1.6 g shim, not
   the 89 g case.
2. Drop both servos into the open wells in `case_lower`, leads out through the cable notch, and
   pick up the flange with M2 self-tappers through the vertical pilot slots. The slots are slots,
   not holes, because clone SG90s vary about 1 mm in where the flange sits. The wells go all the
   way to the floor and their walls stop below the lowest ear, so the shim — not the case — is
   what sets the height.
3. Press a `pinion` onto each horn.
4. Plug the ESP32-S3 into its breadboard and slide the assembly into the rails at the rear. The
   dovetails are handed: pegs on one wall, notches on the other, so it goes in one way round. The
   twin USB-C ports face the **right-hand** wall, where the window is.
5. Lay the `deck` on its ledges, drop both drawers on, and mesh each drawer's own blade with its
   pinion. There is no rack to fit — it prints as part of the drawer.
6. `case_upper` goes on over the three alignment pins. No magnets and no screws.
7. Optional: press `logo_inlay` into the debossed mark on the top face.

---

---

## Flash it

MicroPython on an ESP32-S3. Tested on the board in hand: **MicroPython 1.28.0**, 2.0 MB free heap.
Full detail in [`firmware/README.md`](firmware/README.md).

```sh
PORT=/dev/cu.usbmodem5A790574951          # yours will differ; ls /dev/cu.*
mpremote connect $PORT mkdir :www
for f in config.py servo.py store.py server.py main.py; do
  mpremote connect $PORT cp $f :$f
done
mpremote connect $PORT cp www/index.html :www/index.html
mpremote connect $PORT reset
```

Wiring is four connections:

| | |
|---|---|
| Drawer A servo signal | GPIO 5 |
| Drawer B servo signal | GPIO 6 |
| Servo V+ | **5 V, not the 3V3 rail** |
| Servo GND | common with the ESP32 GND |

Two SG90s stalling together pull well over an amp. Power them from the 5 V pin or a separate
supply — a USB port feeding the 3V3 regulator will brown the board out mid-move and you will spend
an afternoon blaming the code.

### Run it

The cabinet brings up **its own access point**, because a demonstrator has to work in a meeting room
with no guest wifi. Set `JOIN = ("ssid", "password")` in `firmware/config.py` to try an existing
network first and fall back to the AP.

| | |
|---|---|
| SSID | `shopkeeper-NANO` |
| Password | `forge2026` |
| URL | **http://192.168.4.1/** |
| PIN | `2468` — but see below |

**The PIN gate ships disabled.** `REQUIRE_PIN = False` in `firmware/config.py`, because it was in
the way during bench testing. The cabinet as flashed will open either drawer for anyone who loads
the page, and the UI says `pin bypassed — bench mode` rather than pretending otherwise. Set
`REQUIRE_PIN = True` before you demo it to anyone, which is the whole argument of the project.

With it on, the UI locks itself again after two minutes idle. Every open, close, unlock and rejected PIN is
written to an append-only log. `GET /api/state` returns the lot; everything except `/api/state`,
`/api/unlock` and `/api/lock` returns **403** while the cabinet is locked.

To work on the UI without joining the cabinet's AP — which on a laptop means giving up your
internet — run the desktop mock. It serves the real `www/index.html` against a simulated cabinet
and imports the real `config.py`, so the tool lists, PIN, timeouts and servo endpoints are the ones
the hardware actually runs:

```sh
.venv/bin/python firmware/mock_server.py --port 8732
```

---

---

## The terminal

<p align="center">
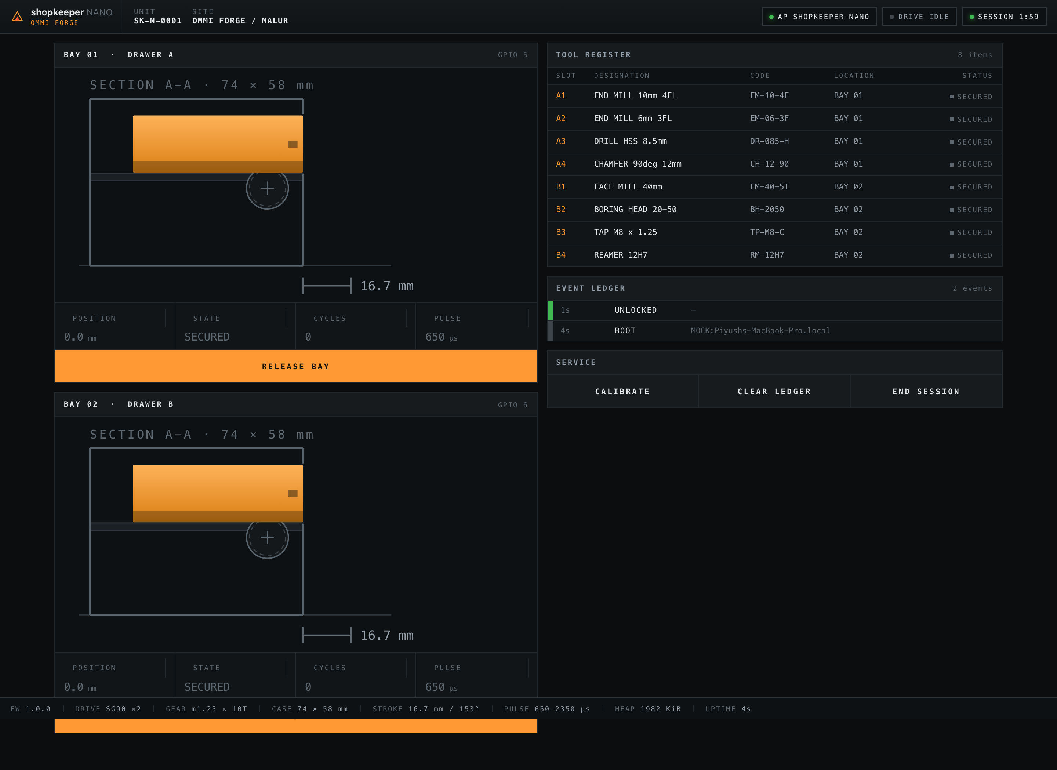
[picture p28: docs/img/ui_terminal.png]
the operator terminal
  
</p>

A machine HMI, not a web app: a live section drawing of each bay with the drawer at its measured
position, the tool register, and an append-only event ledger. Served off the ESP32 itself as a
single 40 KB file with **no CDN, no framework and no network call of any kind** — it has to work in
a meeting room where the cabinet is the only thing on the network.

<table>
<tr>
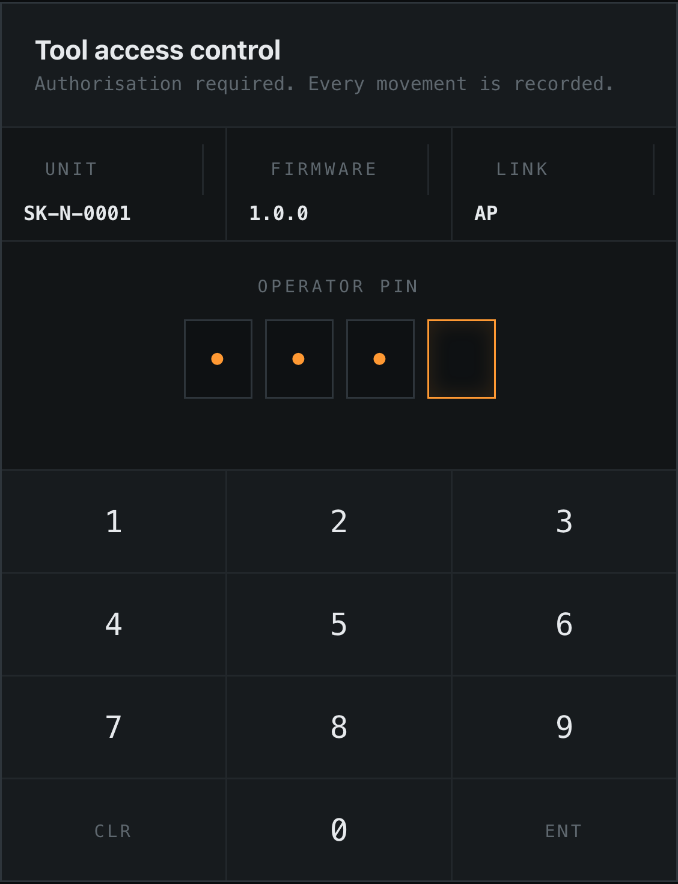
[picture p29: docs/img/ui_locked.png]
the PIN gate
<td width="42%" valign="top"></td>
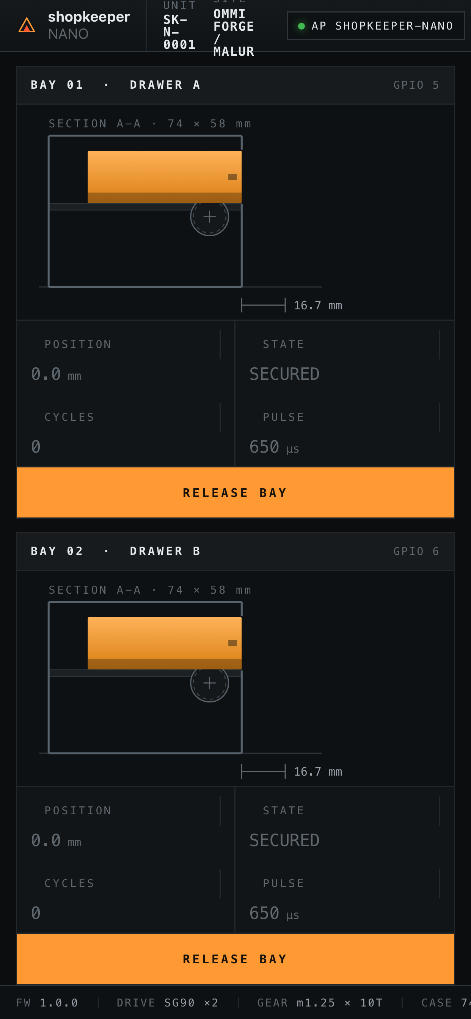
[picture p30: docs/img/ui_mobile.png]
the terminal on a phone
<td width="58%" valign="top"></td>
</tr>
<tr>
<td align="center"><em>the gate — the whole product, in one screen</em></td>
<td align="center"><em>and on the phone that actually opens it</em></td>
</tr>
</table>

Shot by [`tools/shoot_ui.py`](tools/shoot_ui.py) against `firmware/mock_server.py`, which imports
the real `firmware/config.py` — so the register, PIN, timeouts and servo endpoints on screen are the
ones the hardware runs.

---

---

## Print it faster

For a demonstrator that carries no load, the drawer prints in **13m 01s and 6.73 g** instead of
20m 00s and 10.52 g — 35% less time, 36% less PLA — with no dimension changed. Import
`print_profiles/shopkeeper DEMO 0.30.json`, or set four values: layer height 0.30, **1** wall loop,
**0%** infill, 0.8 mm top and bottom shells.

Measured by running the slicer headless across a sweep
([`tools/demo_sweep.py`](tools/demo_sweep.py)), not estimated. Three results worth having:

- **Raising print speed does nothing.** Outer wall 200 → 300 → 400 mm/s changed the time by zero
  seconds; the walls are too short for the head to reach the commanded feedrate.
- **Cutting lightening holes makes it *slower*** — up to +24% for −22% PLA. Deleting infill that is
  already 0% saves two seconds, while the broken-up perimeters push travel and retraction from 62 s
  to 285 s ([`tools/cutout_test.py`](tools/cutout_test.py)).
- **The shipped "0.24mm Standard" preset slices at 0.20.** It carries no layer height of its own and
  inherits one from its base.

For a drawer that will hold real steel, use `print_profiles/shopkeeper PROTOTYPE 0.24.json`
instead — 15m 31s, 8.48 g, two walls.

---

---

## Verify it

On this project the silent failures were the expensive ones, so nothing is trusted twice. Every
checker below **measures the shipped meshes** rather than reading intent out of the source — the
source has been right and the mesh wrong more than once here.

| Command | Asks |
|---|---|
| `.venv/bin/python cad/preflight.py` | **Go/no-go before filament is spent.** Assembles every real mesh in its true pose, adds a solid proxy for the SG90, and boolean-intersects every pair. Anything that overlaps cannot be assembled. Then measures the gear mesh off the geometry and sweeps both drawers through full stroke. |
| `.venv/bin/python cad/meshsim.py` | **Does the gear pair actually turn, at the size the machine prints?** Rolls the pair through a full tooth cycle in 2D at several print growths and reports the tightest gap. Dilating a polygon is exactly what an FDM machine does to a part. |
| `.venv/bin/python cad/fitcheck.py` | **Every mating fit, ray-cast off the real STLs.** Finds the actual hole and slot widths and compares them to the actual peg and blade widths. Bands are for PLA, not PETG — PETG takes an interference fit by deforming, PLA takes it by snapping. |
| `.venv/bin/python cad/overhangs.py` | **What prints into thin air.** For every downward-facing face, cast a ray straight down; if it hits nothing, that face is unsupported. Reports total area and where, so the fix can be geometric rather than "enable supports". |
| `.venv/bin/python cad/tolerances.py` | The same fits computed *from the parameters* — what the design intended, as a cross-check on what it achieved. |

`cad/nano.py` also carries about twenty of its own assertions and refuses to export if any fail:
the pinion is on the rack at both ends of travel, the fin stays keyed in the deck slot, the servo
fits under the deck, the two servos do not clash, the ears stay inside the case, the tooth tip is
printable at ≥0.60 mm, every part is watertight and a single body, and an erosion test finds the
narrowest neck in each part's **first layers** — because watertight and single-body both pass on a
part hanging together by 0.6 mm, which is exactly how the deck once shipped.

### Look at it

`nano/viewer/index.html` is a self-contained interactive 3D viewer built from the real STLs —
13,343 unique triangles, 17,119 drawn per frame assembled, 17,759 exploded. Hand-rolled canvas-2D
painter's-algorithm renderer: no CDN, no external script, no font, no network call of any kind.
Open the file.

### Regenerate

```sh
python3 -m venv .venv
.venv/bin/pip install numpy trimesh manifold3d networkx shapely mapbox_earcut pillow
.venv/bin/python cad/nano.py         # → nano/*.stl + nano/plates/*
```

Every dimension lives in the `P` dict at the top of `cad/nano.py`. Change a number, re-run.

Two things worth knowing before you do:

- `cad/logo.py` traces the debossed mark from a **bitmap on the author's machine**
  (`~/Desktop/Screenshot*5.37*.png`). Point `SRC_GLOB` at your own artwork, or call
  `trace(src=...)`, or the run stops there.
- `preflight.py`, `fitcheck.py`, `meshsim.py` and `tolerances.py` all `import nano`, which re-runs
  the generator — so **running a checker rewrites `nano/`**. That is deliberate (they check what
  shipped, not what was meant), but it means the checkers write to the directory your slicer reads.
  `overhangs.py` and the viewer do not.

---

---

## Repo map

| Path | |
|---|---|
| `nano/*.stl` | **the build** — 9 parts |
| `nano/plates/` | 2 print plates as `.3mf` and `.stl`, plus the one-plate viewing copy |
| `nano/viewer/index.html` | self-contained 3D viewer |
| `cad/nano.py` | the whole machine — parts, assertions, plating |
| `cad/logo.py` | traces the Ommi Forge mark from a bitmap into a debossable polygon |
| `cad/mf3.py` | 3MF writer — trimesh 5.0 emits an empty `<build>` section and drops names |
| `cad/preflight.py` `meshsim.py` `fitcheck.py` `overhangs.py` `tolerances.py` | the checkers |
| `cad/viewer3d.py` `build_page.py` `mounts_page.py` `render_sections.py` | viewer and drawing generators |
| `firmware/` | MicroPython — servo driver, store, HTTP server, UI, desktop mock |
| `cad/cabinet.py` `slidebox.py` `mini.py` `toolcell.py` | superseded generations, see [`docs/history.md`](docs/history.md) |
| `tools/measure_stl.py` | bounding boxes and ray-cast internal cavities of any STL |
| `tools/render.py` | numpy software rasteriser — z-buffer, three-point lighting, planar shadow |
| `tools/make_assets.py` | every image and animation in this README, from the shipped meshes |
| `tools/bay2_endurance.py` | the 60-cycle hardware test |
| `tools/print_sweep.py` `demo_sweep.py` `cutout_test.py` | headless slicer sweeps |
| `tools/shoot_ui.py` | terminal screenshots via headless Chromium |
| `print_profiles/` | Bambu Studio process presets for demo and prototype prints |
| `docs/img/` | rendered stills and animations |

---

## Bill of materials

| | Qty | ₹ |
|---|---|---|
| ESP32-S3 dev board + half-size breadboard | 1 | on hand |
| SG90 servo (MG90S for a pilot) | 2 | on hand |
| M2 self-tapping screws, servo flanges | 4 | ~100 |
| Dupont leads | — | on hand |
| Filament, ~140 g | — | ~120 |
| 0.91″ SSD1306 OLED, I²C *(optional)* | 1 | ~150 |

Runs off a USB power bank, so it sets up on a meeting table with no socket.

The top face carries a 26 × 10 mm window and two 5 mm LED holes. They are **provision**: firmware
1.0.0 is web-UI only and drives neither. The PIN is entered on a phone, which is also how the
original spec's 4×4 keypad disappeared from the BOM.

---

## Sequence and states

### An authorised pick

```mermaid
sequenceDiagram
  autonumber
  participant O as Operator
  participant T as Terminal (phone)
  participant F as Firmware
  participant M as Servo + rack
  participant L as Log

  O->>T: enter PIN
  T->>F: POST /api/unlock
  F-->>T: 200 · session opens, 2 min idle timer
  O->>T: release Bay 1
  T->>F: POST /api/drawer {id:0, open:true}
  F-->>T: 202 accepted
  F->>M: drive 650 → 2350 µs
  F->>L: OPENED · bay 1 · operator
  M-->>F: 16.7 mm out
  Note over T,F: panel and page both switch to WEB CONTROL
  O->>T: secure bay
  T->>F: POST /api/drawer {id:0, open:false}
  F->>L: CLOSED · bay 1
  F-->>T: bay secured
```

The log is written **before** the confirmation goes back, so a move that happened is always
recorded even if the network drops mid-reply. The record is the product; it does not get to
be best-effort.

### What a bay can be

```mermaid
stateDiagram-v2
  [*] --> SECURED
  SECURED --> MOVING: cleared + released
  MOVING --> OPEN: stroke complete
  OPEN --> MOVING: secure
  MOVING --> SECURED: stroke complete
  SECURED --> SECURED: not cleared · logged as REJECTED
```

Four states and no others. There is no drawer-position switch in v1 — the firmware assumes a
commanded move completed, which is honest but not sensed, and a microswitch is the correct
fix at about ₹30.

---

---

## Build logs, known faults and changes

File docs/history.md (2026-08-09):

# Design lineage

The shipping machine is the **NANO** (`cad/nano.py` → `nano/*.stl`). It is the fifth generator in
this repo, and the four before it are still here, still runnable, and still described below.

They are kept deliberately. The pitch this project makes is a provenance argument — *we know why
every number is what it is* — and half of that evidence is the record of the numbers that were
wrong. Each generation was killed by something specific, and the thing that killed it is the
reason the next one is shaped the way it is.

| Generation | Script | Envelope | Mechanism | Killed by |
|---|---|---|---|---|
| ToolCell insert | `cad/toolcell.py` | fits a 172.6 × 91 × 52 mm drawer | hinged flap on the servo horn | depended on somebody else's toolbox |
| ToolCell cabinet | `cad/cabinet.py` | 216 × 136 × 169 mm | m1.5 × 24T, sliding **lids**, 56.5 mm | a lid that opens half a bin is not a drawer |
| slidebox | `cad/slidebox.py` | 216 × 136 × 269 mm | m1.5 × 24T, sliding **drawers**, 56.5 mm | too big to carry to a meeting |
| shopkeeper MINI | `cad/mini.py` | 120 × 90 × 80 mm | m1.5 × 14T, 33.0 mm | one drawer cannot demonstrate access *control* |
| **shopkeeper NANO** | `cad/nano.py` | **92 × 74 × 66 mm** | **m1.25 × 16T, 31.42 mm** | — current |

---

## 1. ToolCell insert — `cad/toolcell.py`

A parametric generator for parts that drop into the large drawer of a **Ryobi Mini Desktop
Toolbox**. Frame of reference was drawer-local: 172.6 mm across, 91 mm deep, 52 mm of height to
play with, with 1.0 mm of total side-to-side slack so the carrier could be dropped in.

Four compartments in one carrier, two of them live, each closed by a hinged flap driven straight
off an SG90 horn.

It went because the whole proposition rests on the machine being *ours*. A demonstrator built
inside a retail toolbox invites the question of what happens when that toolbox is discontinued,
and it caps every dimension at somebody else's mould.

## 2. ToolCell cabinet — `cad/cabinet.py`

The first purpose-built enclosure. Nothing in it depends on the Ryobi model; every dimension is
derived from the mechanism outward, so the parts are guaranteed to fit each other.

A three-module stack, 216 × 136 mm on the floor, printable on a 256 mm bed:

```
   control head    42 mm   4×4 keypad on top, 0.91" OLED in front, tablet cradle
   drawer bay      60 mm   the live drawer — two bins, two servos
   electronics bay 55 mm   ESP32-S3, 5 V supply, terminal blocks
   feet            12 mm
                  ------
                  169 mm
```

Each bin is **99 × 75 × 32 mm** and closed by a lid that **slides** on a rack driven by an SG90
through a printed 24-tooth pinion. 180° of servo gives 56.5 mm of travel, opening 57% of the bin.

An ESP32-S3 runs its own WiFi access point and serves the operator kiosk to any phone or tablet —
no router, no internet, no laptop. That decision survived into the NANO unchanged.

### Why sliding lids, not hinged flaps

This is the argument that killed generation 1, and it is worth keeping in full because it is the
first time measurement beat intuition on this project.

The first design used a hinged flap driven straight off the servo. It worked on paper and was
wrong in practice: a flap that opens 66° rises **76 mm above the drawer**, so the drawer had to be
pulled its full 105 mm out every single time. Anything less and the servo drives the flap into the
underside of the bay above and strips its nylon gears.

Sliding needs **zero vertical clearance**. Drawer position stops mattering, the servo can never
stall against an obstruction, and the interlock switch and limit stop both disappear from the BOM.

It also gives something for free: the two lids ride at different heights and slide over one
another, so **only one bin can be open at a time** — which is exactly what the commercial cabinets
enforce.

The cost is that a lid opens about half its bin rather than swinging fully clear. That cost is what
eventually retired this design: a lid that slides halfway off a fixed box reads, in a room, as a
box with a broken lid. Nobody watching it says *that machine just gave me a tool*.

## 3. slidebox — `cad/slidebox.py`

The idea that fixed it: stop moving the lid and **move the drawer**.

A toothed fin hangs from the drawer's underside through a slot in the bay deck. A vertical-shaft
SG90 sits under the deck with a 24-tooth pinion on it, and 180° of servo becomes 56.5 mm of drawer
travel. Nothing rises above the cabinet and the drawer cannot escape — at full travel, 69 mm of a
126 mm drawer is still captured by the bay.

```
   head            45   4×4 keypad, 0.91" OLED, tablet cradle
   drawer bay A    81   motorised drawer
   drawer bay B    81   motorised drawer
   electronics     50   ESP32-S3, 5 V supply, terminal blocks
   feet            12
                  ---
                  269 mm tall, 216 × 136 footprint
```

The drive scheme is the one the NANO still uses. The enclosure was the problem: `case_base` alone
generates at 279 g, the whole build is over a kilogram of filament and the better part of two days
on the plate, and a demonstrator that cannot be carried into a meeting under one arm does not get
demonstrated.

## 4. shopkeeper MINI — `cad/mini.py`

Smallest credible motorised-drawer demonstrator. One module, one drawer that drives itself out,
everything inside. 120 × 90 × 80 mm.

```
   top plate    keypad recess, 0.91" OLED in the front face
   drawer       driven out 33 mm by an SG90 through a 14T pinion
   deck         drawer runs on it, slotted for the drive fin
   mech bay     SG90 (shaft up) + pinion + ESP32-S3 + wiring
```

m1.5 × 14 teeth, pitch radius 10.5, so half a turn is 33.0 mm. The drawer is 111.8 × 77.5 × 28 mm.
As generated, `case` + `drawer` + `pinion` come to 217 g.

Meshes are still in `mini/`, including a plate.

It went for a reason that is commercial rather than mechanical. **One drawer cannot demonstrate
access control.** The entire pitch is *the one drawer you are cleared for opens and the other one
does not* — and with a single drawer there is no other one. A machine with two drawers makes the
argument by itself, without a slide.

## 5. shopkeeper NANO — `cad/nano.py`

Current. See the [README](../README.md).

Two drawers **side by side** rather than stacked, so one mechanism deck serves both. Stacking would
have doubled the height, because a vertical SG90 costs 26 mm of dead space under every deck.

Gearing dropped from m1.5 × 14T to m1.25 × 16T — a smaller module for a smaller case, more teeth to
hold the pitch radius near 10 mm and keep half a turn worth 31.42 mm of travel. That change forced
**stub teeth** (0.8 module addendum instead of 1.0): a full-depth involute at m1.25 comes to a
0.45 mm tip, which is under one extrusion width, so the machine rounds it off and the contact it
was supposed to make never happens.

---

## What each generation taught the next

- **Insert → cabinet.** Own the enclosure, or the product is a fixture on someone else's part.
- **Cabinet → slidebox.** Move the drawer, not the lid. A machine that hands you a tool is a
  different object from a box whose lid slid halfway open.
- **Slidebox → MINI.** Portable beats impressive. The unit has to be carried into the room.
- **MINI → NANO.** Two drawers, because the product being sold is *which one opens*.
- **All of them → the checkers.** `cad/preflight.py`, `cad/meshsim.py`, `cad/fitcheck.py` and
  `cad/overhangs.py` exist because on every one of these generations the source was right and the
  mesh was wrong at least once. They measure the shipped STLs rather than reading intent out of the
  parameters. `cad/tolerances.py` used to keep its own copy of the parameters "so it is readable on
  its own"; that copy silently froze two revisions back and printed a clean audit of a case that no
  longer existed.

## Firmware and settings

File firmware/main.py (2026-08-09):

"""
shopkeeper NANO — entry point.

Brings up the network, restores calibration, starts the servos in the closed
position and serves the UI. Written so that a failure anywhere still leaves a
reachable cabinet: if the wifi join fails it falls back to its own AP, and if
the AP fails too it keeps serving on whatever interface came up.
"""
try:
    import asyncio
except ImportError:
    import uasyncio as asyncio

import gc
import network
import time

import config
import store
from servo import Servo
from server import App, serve

try:
    import sh1106
    import hud
except ImportError:      # a cabinet with no screen is still a cabinet
    sh1106 = hud = None


def _banner(*rows):
    # str.ljust does not exist in MicroPython - pad by hand
    w = max(len(r) for r in rows)
    print("+" + "-" * (w + 2) + "+")
    for r in rows:
        print("| " + r + " " * (w - len(r)) + " |")
    print("+" + "-" * (w + 2) + "+")


def bring_up_network():
    """Returns (mode, ip). Tries to join a known network first if one is
    configured, because a cabinet on the shop wifi is reachable from a laptop
    that also needs the internet. Falls back to its own AP, which is what
    actually gets used in a meeting room."""
    if config.JOIN:
        ssid, pw = config.JOIN
        sta = network.WLAN(network.STA_IF)
        sta.active(True)
        if not sta.isconnected():
            sta.connect(ssid, pw)
            t0 = time.ticks_ms()
            while not sta.isconnected():
                if time.ticks_diff(time.ticks_ms(), t0) > config.JOIN_TIMEOUT_S * 1000:
                    break
                time.sleep_ms(200)
        if sta.isconnected():
            return "STA:" + ssid, sta.ifconfig()[0]
        sta.active(False)

    ap = network.WLAN(network.AP_IF)
    ap.active(True)
    try:
        ap.config(essid=config.AP_SSID, password=config.AP_PASSWORD,
                  authmode=network.AUTH_WPA_WPA2_PSK)
    except Exception:
        ap.config(essid=config.AP_SSID)          # open, if WPA is refused
    t0 = time.ticks_ms()
    while not ap.active() and time.ticks_diff(time.ticks_ms(), t0) < 4000:
        time.sleep_ms(100)
    return "AP:" + config.AP_SSID, ap.ifconfig()[0]


async def _housekeeping(app):
    """One place that owns the slow, boring, must-not-be-forgotten work."""
    while True:
        await asyncio.sleep(5)
        app.log.maybe_flush()
        gc.collect()


def _hms(sec):
    sec = int(sec)
    if sec < 60:
        return str(sec) + "s"
    if sec < 3600:
        return "%dm %02ds" % (sec // 60, sec % 60)
    return "%dh %02dm" % (sec // 3600, (sec % 3600) // 60)


def _hud_ctx(app, ip, mode):
    """The same numbers the web terminal serves, shaped for a 128x64 panel.

    Read off app/servo state rather than kept in parallel - a display that
    disagrees with the page it sits next to is worse than no display."""
    ds = [d.state() for d in app.drawers]
    ev = app.log.entries
    up = time.time() - app.boot_at
    return {
        "unit": "SK-N-0001",
        "link": mode.split(":")[0] if mode else "-",
        "ssid": config.AP_SSID,
        "ip": ip,
        "cycles": sum(x["cycles"] for x in ds),
        "uptime": _hms(up),
        "heap": str(gc.mem_free() // 1024) + "K",
        "tools": len(getattr(config, "TOOLS", ()) or ()) or 8,
        "events": len(ev),
        "travel_mm": ds[0]["travel_mm"] if ds else 16.7,
        "bays": [("BAY " + str(i + 1), x["pos"],
                  "OPEN" if x["open"] else "SHUT") for i, x in enumerate(ds)],
        "log": [(_hms(max(0, up - e.get("up", up))), e.get("what", "")[:8])
                for e in ev[:3]],
        "test_cycles": getattr(config, "TEST_CYCLES", 0),
        "test_fail": getattr(config, "TEST_FAILURES", 0),
        "moving_label": "BAY 1",
        "moving_pos": 0.0,
    }


async def _demo(app):
    """The unattended performance: hold a card, open bay one, open bay two,
    secure both, hand back to the attract loop.

    app.demo is set BEFORE each move and cleared after, so the panel always
    leads the hardware. It drives the servos through the same Servo.move() the
    HTTP handler uses and writes the same log entries, so a demo open is a real
    open - the ledger does not get a special case it can lie in."""
    await asyncio.sleep(2)
    while True:
        # Stand down while a person is driving. Two things moving the same
        # drawer for different reasons is how a demo embarrasses you.
        while getattr(app, "cmd", None):
            await asyncio.sleep_ms(300)
        t0 = time.time()
        while True:
            if getattr(app, "cmd", None):
                break                                # somebody took over
            left = config.DEMO_HOLD_S - (time.time() - t0)
            if left <= 0:
                break
            app.demo = {"stage": "HOLD", "left": left + 1,
                        "frac": 1.0 - left / config.DEMO_HOLD_S,
                        "tag": "%ds" % int(left + 1)}
            await asyncio.sleep_ms(200)

        for i, dr in enumerate(app.drawers):          # open one, then the other
            app.demo = {"stage": "OPEN", "label": "BAY " + str(i + 1),
                        "pos": dr.pos, "tag": "%d/%d" % (i + 1, len(app.drawers))}
            await dr.move(True)
            app.log.add("OPENED", dr.id, "demo")
            app.demo = {"stage": "OPEN", "label": "BAY " + str(i + 1),
                        "pos": 1.0, "tag": "OPEN"}
            await asyncio.sleep(config.DEMO_DWELL_S)

        for i, dr in enumerate(app.drawers):          # then put it all back
            app.demo = {"stage": "CLOSE", "label": "BAY " + str(i + 1),
                        "pos": dr.pos, "tag": "SECURE"}
            await dr.move(False)
            app.log.add("CLOSED", dr.id, "demo")
            app.demo = {"stage": "CLOSE", "label": "BAY " + str(i + 1),
                        "pos": 0.0, "tag": "SECURE"}
            await asyncio.sleep(1)

        app.demo = None
        if not config.DEMO_LOOP:
            return
        await asyncio.sleep(config.DEMO_GAP_S)        # attract loop takes over


async def _display(app, d, ip, mode):
    """Runs forever. Never stops, never blanks.

    The first version wrapped the whole loop in one try/except and called
    poweroff() on the way out - so a single bad frame killed the panel until
    the next reboot, which is exactly the "goes black after a while" symptom.
    A display task that can die is worse than no display task: the cabinet
    looks broken while working perfectly.

    Now each frame is guarded on its own, a run of failures re-attaches the
    panel rather than giving up, and there is no code path that turns it off.
    The module browns out and latches under load - see sh1106.py - so losing
    it for a few seconds is normal and recovery has to be automatic."""
    loop = hud.Loop(d, dwell=config.OLED_DWELL)
    fails = 0
    while True:
        try:
            ctx = _hud_ctx(app, ip, mode)
            ctx["demo"] = getattr(app, "demo", None)
            # PRIORITY. A person pressing a button beats everything the
            # cabinet does of its own accord - including the scripted demo.
            # Whatever is on the panel, a web command takes it over at once and
            # holds it until the move finishes plus four seconds, so the
            # outcome is seen and not just the motion.
            #   web command  >  scripted demo  >  moving  >  locked  >  attract
            cmd = getattr(app, "cmd", None)
            if cmd:
                live = [sv for sv in app.drawers if sv.id == cmd.get("id")]
                if live and live[0].busy:
                    cmd["pos"] = live[0].pos
                if (not cmd.get("done")) or (time.time() - cmd.get("at", 0)) < 4:
                    ctx["cmd"] = cmd
                    loop.tick(ctx, hud.s_web)
                    fails = 0
                    await asyncio.sleep_ms(50)
                    continue
                app.cmd = None
            if ctx["demo"]:
                loop.tick(ctx, hud.s_demo)          # the script owns it next
                fails = 0
                await asyncio.sleep_ms(60)
                continue
            over = None
            for i, x in enumerate([sv.state() for sv in app.drawers]):
                if x["busy"]:
                    ctx["moving_label"] = "BAY " + str(i + 1)
                    ctx["moving_pos"] = x["pos"]
                    over = hud.s_moving
                    break
            if over is None and app.locked:
                over = hud.s_lock
            loop.tick(ctx, over)
            fails = 0
            await asyncio.sleep_ms(40 if over else 90)
        except Exception as e:
            fails += 1
            if fails in (1, 25):
                print("display hiccup (%d):" % fails, e)
            if fails >= 25:
                # the panel has probably browned out and latched; rebuild it
                try:
                    nd = sh1106.attach()
                    if nd:
                        d = nd
                        loop = hud.Loop(d, dwell=config.OLED_DWELL)
                        fails = 0
                        print("display re-attached")
                except Exception:
                    pass
            await asyncio.sleep_ms(400)


async def _amain():
    mode, ip = bring_up_network()

    # Attach the display BEFORE anything moves. Parking the drawers is the
    # peak current draw of the machine, and scanning for the panel during it
    # finds nothing.
    disp = sh1106.attach() if sh1106 else None

    drawers = [Servo(spec) for spec in config.DRAWERS]
    cal = store.load_cal()
    for d in drawers:
        got = cal.get(str(d.id))
        if got:
            d.calibrate(got[0], got[1])

    # Park closed at boot. The drawers may well be sitting open from last time,
    # and a cabinet whose UI says CLOSED while the drawer is out is worse than
    # one that moves unexpectedly on power-up.
    for d in drawers:
        await d.move(False, ms=700)

    log = store.Log()
    log.add("BOOT", None, mode)
    app = App(drawers, log)
    app.net = mode

    await serve(app)
    asyncio.create_task(_housekeeping(app))
    app.demo = None
    if getattr(config, "DEMO", False):
        asyncio.create_task(_demo(app))
        print("demo: scripted, %ds hold then both bays" % config.DEMO_HOLD_S)

    if disp:
        # Boot card. Uses SCREENS[0] rather than naming a screen: the set gets
        # reordered and renamed as the pitch changes, and a stale name here
        # crashes main and leaves the cabinet at a REPL prompt with no server.
        hud.SCREENS[0](disp, 1.0, {"link": mode.split(":")[0]})
        disp.show()
        asyncio.create_task(_display(app, disp, ip, mode))
        print("display: SH1106 on SCL%d/SDA%d" % (config.OLED_SCL, config.OLED_SDA))
    else:
        print("display: none")

    _banner("shopkeeper NANO",
            "net    " + mode,
            "open   http://" + ip + "/",
            "pin    " + ("*" * len(str(config.PIN))),
            "free   {} bytes".format(gc.mem_free()))

    while True:
        await asyncio.sleep(3600)


def run():
    try:
        asyncio.run(_amain())
    finally:
        asyncio.new_event_loop()


run()

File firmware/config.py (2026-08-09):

"""
shopkeeper NANO — configuration.

Everything a given unit needs to differ on lives here, so no other file has to
be edited per build. Calibration written from the web UI is persisted to
/data/cal.json and overrides the defaults below at boot.
"""
import math


# ── network ────────────────────────────────────────────────────────────────
# AP is the default on purpose. A demonstrator has to work on a shop floor and
# in a meeting room with no guest wifi, so the cabinet brings its own network
# and the salesperson's phone joins it. Set JOIN to a (ssid, password) tuple to
# also try an existing network first.
AP_SSID     = "shopkeeper-NANO"
AP_PASSWORD = "forge2026"          # >= 8 chars or the ESP refuses to start the AP
# Joining the house network first means the cabinet is reachable from a laptop
# that is also on the internet. Falls back to its own AP if the join fails, so
# the meeting-room case still works.
#
# CREDENTIALS DO NOT LIVE IN THIS FILE. This is a public repository and a real
# SSID and password were committed here once already. secrets.py is gitignored;
# copy secrets_example.py to secrets.py and put them there.
try:
    from secrets import JOIN
except ImportError:
    JOIN = None                    # no secrets.py -> AP mode only, which is safe
JOIN_TIMEOUT_S = 12

# ── servos ─────────────────────────────────────────────────────────────────
# Pulse widths, microseconds. An SG90 nominally spans 500..2500 us for 180 deg,
# but clones reach 160-175 before they stall against their own end stop and
# start cooking, so the defaults deliberately ask for less than the mechanism
# can do.
#
#   span_us / 2000 * 180 = degrees,  degrees / 180 * TRAVEL_MM = mm of drawer
#   650..2350  ->  1700 us  ->  153 deg  ->  16.69 mm of the 19.63 available
#
# (An earlier comment here claimed 700..2300 was 160 deg. It is 144. The
# arithmetic is written out above so the next person can check it.)
#
# The web UI writes these live, so calibrate against the real drawer rather
# than trusting the numbers here.
# ── the gear, in ONE place ─────────────────────────────────────────────────
# This number was written out by hand in servo.py, again in mock_server.py, and
# a third time as a tooth count in www/index.html. When cad/nano.py went from
# 16 teeth to 10 none of the three moved, so the firmware reported a 26.7 mm
# stroke for a drawer that travels 16.69 and the terminal's footer advertised a
# gear the machine does not have. Derived once here; everything else imports it.
MODULE   = 1.25
TEETH    = 10
PITCH_R  = MODULE * TEETH / 2.0          # 6.25 mm
TRAVEL_MM = math.pi * PITCH_R            # 19.63 mm for a full 180 deg

SERVO_FREQ_HZ = 50
DRAWERS = [
    {"id": 0, "name": "Drawer A", "pin": 5,  "closed_us": 650, "open_us": 2350},
    {"id": 1, "name": "Drawer B", "pin": 6,  "closed_us": 650, "open_us": 2350},
]

# How long a full open or close takes. The mechanism does not need easing to
# survive - 17.6 N against a 0.06 N load - but a drawer that glides reads as a
# product and a drawer that snaps reads as a toy.
TRAVEL_MS = 1100

# An SG90 hunts audibly when it is holding position and gets warm doing it. The
# rack and pinion is not backdriveable enough to matter over a demo, so cut the
# signal once the move has settled.
DETACH_AFTER_MS = 450

# ── scripted demo ──────────────────────────────────────────────────────────
# An unattended performance for a table: hold a card, open one bay, open the
# other, secure both, then hand back to the attract loop. Runs itself at boot
# so the cabinet does something the moment it is powered, and can be re-armed
# from the terminal with POST /api/demo.
DEMO          = True
DEMO_HOLD_S   = 15      # the card sits this long before anything moves
DEMO_DWELL_S  = 3       # pause with a bay open, so the eye catches up
DEMO_LOOP     = True    # run again after finishing
DEMO_GAP_S    = 25      # attract loop gets this long between performances

# ── bench record ───────────────────────────────────────────────────────────
# What the VERIFIED screen shows. These are not aspirational: each number is
# the confirmed total from tools/bay2_endurance.py runs, whose JSON reports are
# the evidence. A cycle counts only if the harness polled until busy cleared
# AND the drawer's own open flag flipped - the API returns 202 the moment it
# accepts a job, so counting requests would prove nothing.
# Raise these when a run finishes, never before.
#   60  bay 2, sequential
#  100  bay 1  ) both bays driven SIMULTANEOUSLY, which is the worst case
#  100  bay 2  ) for supply sag - no brownout, no reboot, 0 failures
TEST_CYCLES   = 260
TEST_FAILURES = 0
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

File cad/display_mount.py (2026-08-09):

#!/usr/bin/env python3
"""
shopkeeper NANO — DISPLAY MOUNT v0.3

A 1.3" SH1106 and two status lamps, on a pod that sits on case_upper.

    THE LID DOES NOT CHANGE. Not one cut.
    NO SUPPORTS. Both parts print flat on their own faces.
    NO LATCH. Two spigots in two holes, the way the lid itself is located.
    FULL WIDTH. The pod is 92 mm, flush with the case sides.

The pod registers on three features the top face already has, verified against
nano/case_upper.stl rather than trusted from the source:

    dia 5.00 hole   (20.00, 45.88)  ]  registration
    26 x 10 window  (46.00, 45.88)  ]  wire pass
    dia 5.00 hole   (72.00, 45.88)  ]

WHY THE LAMPS ARE ON THE POD AND NOT IN THE LID
The lid's two dia 5 holes were drawn as provision and never checked against
the bay. A 5 mm LED body is 8.6 mm long; pushed up from below with its dome
flush it hangs from z 64 down to z 55.9 - through the drawer top at z 60 and
through the anti-tip rib whose crown is at z 62. A 3 mm LED still fouls the
rib. Nothing may protrude past the ceiling at x 20 or x 72 at all, so the
spigots are exactly PLATE_T tall and stop flush.

HOW THE SCREEN MOUNTS
Through its own four dia 3.00 corner holes, on four printed pegs, behind ONE
opening cut straight through the face wall. No PCB pocket, no glass relief, no
bezel stack, no retainer, no screws: the board's own front face seats on the
wall's inner surface, which overlaps it by 4.90 mm top and bottom, and the
pegs locate it. That deleted most of v0.2.

WHY TWO PARTS
    base   prints SPIGOT-SIDE UP, flat on the bed. Every downward feature
           becomes an upward one.
    body   prints FACE-DOWN. The bezel forms against the bed - the same trick
           case_upper uses for the logo - the mating face becomes an UP-facing
           slope, and the pegs and lamp bores point straight up off it.

    A one-piece pod has no such orientation: face-down puts the lid-mating
    surface at TILT to the bed as a stepped slope, and base-down stands the
    whole plate on two 2 mm spigots.

WHAT IS STILL BROKEN, AND IT IS NOT IN THIS FILE
There is no route from the pod to the ESP32. `deck()` in nano.py is a solid
plate; ray-casting 1800 points down through the wire slot, NOT ONE reaches
past it in the only drawer-free band (x 42-49). The 210 rays that do get
through the deck elsewhere all land in drawer 2's drive-fin slot, where the
rack sweeps 31.4 mm. Until deck() gets a cable hole at x 43-49, this display
cannot be connected to anything. The check at the bottom of this file fails on
purpose and should keep failing until that is fixed.
"""
import os, math
import numpy as np
import trimesh
from trimesh.creation import box, cylinder, extrude_polygon
from shapely.geometry import Polygon
from mf3 import write_3mf, verify

HERE = os.path.dirname(os.path.abspath(__file__))
NANO = os.path.normpath(os.path.join(HERE, "..", "nano"))
OUT  = os.path.join(NANO, "mount")
POSE = os.path.join(OUT, "printpose")
for d in (OUT, POSE):
    os.makedirs(d, exist_ok=True)

# ── THE LID, AS BUILT ──────────────────────────────────────────────────────
# case_upper local coords: z 0 is the deck-mating rim, z 24 is the top face.
# Pod coords share x and y with the case and put z 0 AT THE TOP FACE, so a
# negative z is inside the lid.
CASE_W, CASE_D = 92.0, 74.0
LID_H     = 24.0
PLATE_T   = 2.0                   # top plate -> ceiling at pod z -2.0
HOLE_D    = 5.00
HOLE_X    = (20.00, 72.00)
DATUM_Y   = 45.88                 # all three features sit on this line
WIN       = (33.00, 59.00, 40.88, 50.88)     # x0, x1, y0, y1
# Both of these are 0.2 mm lower than nano.py's DR_TOP implies, because the
# drawer is ASSEMBLED at DECK+0.2, not at DECK. Verified off drawer.stl.
DRAWER_Z  = -5.80                 # drawer top         (assembly z 60.20)
RIB_Z     = -3.80                 # anti-tip rib crown (assembly z 62.20)
CEIL_Z    = -PLATE_T              # bay ceiling        (assembly z 64.00)
NO_DRAWER = (42.00, 49.00)        # the only x band no drawer ever crosses
# deck.stl is exported translated to its own origin; put it back in case coords
WL_DECK_X, WL_DECK_Y = 2.3, 2.3
LOGO_Y1   = 14.5                  # rear edge of the debossed mark
VENT_Y0   = 72.0                  # rear vent windows start here

# ── THE MODULE: 1.3" SH1106 ────────────────────────────────────────────────
# From the MANUFACTURER'S DIMENSIONED DRAWING (Zhengzhou Zhongjingyuan), which
# LCDWIKI's drawing and Pololu's - the latter drawn independently off a
# physical unit - agree with to the hundredth of a millimetre. Every chain in
# it closes exactly, which is why it is believed over a caliper reading:
#     inset 2.50 all round:  35.40 - 5.00 = 30.40,  33.50 - 5.00 = 28.50
#     active area vertical:   7.35 + 14.70 + 11.45 = 33.50
#     glass:                  5.25 + 23.00 +  5.25 = 33.50
#
# TWO CALIPER READINGS TURNED OUT WRONG, and both would have cost the print:
#   - the holes are dia 3.00 (M3), NOT 4.0. The 4.0-4.5 reading is the COPPER
#     ANNULUS around the hole. A 3.9 peg would not have entered at all.
#   - the board is 35.40 wide, not 35.0. (The 33.50 reading was exact.)
PCB_W, PCB_H, PCB_T      = 35.40, 33.50, 1.20
MOD_HOLE_D               = 3.00   # M3 clearance, on a dia 4.50 copper ring
MOD_PITCH_X, MOD_PITCH_Y = 30.40, 28.50
GLASS_W, GLASS_H, GLASS_T = 34.50, 23.00, 1.50   # glass stands 1.4-1.5 proud
ACT_W, ACT_H              = 29.42, 14.70
# THE ACTIVE AREA IS NOT CENTRED ON THE BOARD. It sits 7.35 from the header
# edge and 11.45 from the other, i.e. 2.05 mm toward the header. The glass IS
# centred - the offset is inside the panel, where the driver IC and the FPC
# bond eat the bottom 6.20 mm. A symmetric window clips the picture, and it
# clips it at the top, which is where the status line goes.
ACT_OFF                   = 2.05  # toward the header edge = UP the slope
# The FPC wraps around the edge OPPOSITE the header and folds behind the
# board: a 14 mm band at the centre of that edge, reaching 4 mm in from the
# edge and standing ~1.5 mm off the back. FPC_D was declared as a hard
# clearance and then used by nothing; it is now a face of module_solid().
FPC_W, FPC_D, FPC_T       = 14.0, 4.0, 1.5
# The header: 4 pins on 2.54, centred, row 2.00 mm in from the header edge.
# A Dupont housing on those pins reaches 11.30 mm from the GLASS FACE, which
# is the number that decides how deep the pod has to be behind the screen.
HDR_W, HDR_T              = 12.5, 3.2
HDR_TIP_FROM_GLASS        = 11.30
# A STRAIGHT DUPONT DOES NOT FIT AND CANNOT BE MADE TO. Measured behind an
# up-slope header there is 4.80 mm to the shell, 7.40 mm a millimetre in. A
# 4-way Dupont is ~14.7 mm; even a bare 0.1" male header is ~8.5 mm. Making the
# pod swallow it needs either a deeper pod or a hole out of the back, and the
# hole is what it had - the connector protruded 0.52 mm through the notch.
# So the module is wired one of the two ways that measurably DO fit:
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

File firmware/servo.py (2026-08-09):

"""
SG90 driver.

Two things here are not obvious and both were learned the hard way on hobby
servos:

1. A hobby servo holds position by hunting - it never stops correcting, so it
   buzzes and draws current forever. Cutting the signal after the move lets it
   go quiet. The rack and pinion is not backdriveable enough for a drawer to
   creep open on its own, so nothing is lost by doing it.

2. Commanding the full 500..2500 us span asks for 180 deg, and most SG90 clones
   physically reach 160-175 before the output arm hits its own end stop. Past
   that the pot is out of range, the loop never reaches its target, and the
   motor stalls at full current until something gives. So the endpoints are
   configuration, not constants, and the defaults are deliberately short.
"""
try:
    import asyncio
except ImportError:                      # MicroPython < 1.21
    import uasyncio as asyncio

from machine import Pin, PWM
import config


def _ease(t):
    """Cubic in-out. A drawer that glides reads as a product."""
    if t < 0.5:
        return 4 * t * t * t
    p = -2 * t + 2
    return 1 - (p * p * p) / 2


class Servo:
    def __init__(self, spec):
        self.id = spec["id"]
        self.name = spec["name"]
        self.pin = spec["pin"]
        self.closed_us = spec["closed_us"]
        self.open_us = spec["open_us"]
        self._pwm = None
        self._us = self.closed_us
        self.is_open = False
        self.busy = False
        self.cycles = 0            # completed opens, for the maintenance readout
        Pin(self.pin, Pin.OUT).value(0)   # defined from the very first moment
        self.pos = 0.0             # 0..1 through the stroke, live during a move
        self.walking = False       # a limit search is in progress
        self.walk_stop = False
        self.walk_hit = None
        self._detach_task = None

    # ── low level ─────────────────────────────────────────────────────────
    def _attach(self):
        if self._pwm is None:
            self._pwm = PWM(Pin(self.pin), freq=config.SERVO_FREQ_HZ)

    def detach(self):
        """Stop driving, but HOLD THE LINE LOW - never leave it floating.

        deinit() alone returns the pin to high-impedance. A servo whose signal
        wire is floating picks up noise off the neighbouring wire and twitches,
        which looks exactly like "the other drawer moved too" - and that is a
        far more convincing bug than it deserves to be, because the servo that
        was actually commanded really did move at the same moment.

        A steady low is not a valid servo frame, so the servo simply holds
        station and stays quiet."""
        if self._pwm is not None:
            try:
                self._pwm.deinit()
            except Exception:
                pass
            self._pwm = None
        try:
            Pin(self.pin, Pin.OUT).value(0)
        except Exception:
            pass

    def _write_us(self, us):
        lo = min(self.closed_us, self.open_us) - 1
        hi = max(self.closed_us, self.open_us) + 1
        if us < lo:
            us = lo
        elif us > hi:
            us = hi
        self._attach()
        # duty_ns is exact; duty_u16 quantises the pulse badly at 50 Hz
        try:
            self._pwm.duty_ns(int(us * 1000))
        except AttributeError:
            self._pwm.duty_u16(int(us * 65535 * config.SERVO_FREQ_HZ / 1_000_000))
        self._us = us

    # ── moves ─────────────────────────────────────────────────────────────
    async def _glide(self, to_us, ms):
        frm = self._us
        if frm == to_us:
            self._write_us(to_us)
            return
        steps = max(8, int(ms / 20))
        span = self.open_us - self.closed_us
        for i in range(steps + 1):
            us = frm + (to_us - frm) * _ease(i / steps)
            self._write_us(us)
            # live stroke fraction, so the UI can draw the drawer where it
            # actually is rather than only where it will end up
            self.pos = 0.0 if span == 0 else (us - self.closed_us) / span
            await asyncio.sleep_ms(int(ms / steps))

    async def _settle_then_detach(self):
        await asyncio.sleep_ms(config.DETACH_AFTER_MS)
        self.detach()

    async def move(self, opened, ms=None):
        """Drive to the open or closed endpoint. Returns when the move is done;
        the detach happens on its own afterwards."""
        if self.busy:
            return False
        self.busy = True
        try:
            await self._glide(self.open_us if opened else self.closed_us,
                              config.TRAVEL_MS if ms is None else ms)
            self.is_open = opened
            self.pos = 1.0 if opened else 0.0
            if opened:
                self.cycles += 1
        finally:
            self.busy = False
        asyncio.create_task(self._settle_then_detach())
        return True

    async def walk(self, up, step=25, dwell_ms=240, lo=500, hi=2500):
        """Creep outward from centre until told to stop.

        This is how the limits get found. The ESP32 cannot sense a stall - an
        SG90 is open loop, there is no encoder and no shunt - so the machine
        drives the search and a human supplies the one bit of information the
        hardware physically cannot: "that is as far as it goes". Everything
        after that (backoff, travel, sweep angle, persistence) is automatic.

        Deliberately slow: 25 us a step with a 240 ms dwell is about 2 deg per
        third of a second, which is slow enough to hear the motor change note
        before any damage is done."""
        if self.busy or self.walking:
            return False
        self.busy = True
        self.walking = True
        self.walk_stop = False
        self.walk_hit = None
        try:
            us = 1500
            self._write_us(us)
            await asyncio.sleep_ms(500)
            while not self.walk_stop:
                us = us + step if up else us - step
                if us > hi or us < lo:
                    self.walk_hit = hi if up else lo      # hit the electrical end
                    break
                self._write_us(us)
                await asyncio.sleep_ms(dwell_ms)
            if self.walk_hit is None:
                self.walk_hit = int(self._us)
        finally:
            self.walking = False
            self.busy = False
        asyncio.create_task(self._settle_then_detach())
        return True

    def mark(self, backoff=60):
        """Stop the walk and take the current position as the limit, minus a
        safety backoff so the servo never sits on its own end stop."""
        if not self.walking:
            return None
        self.walk_stop = True
        raw = int(self._us)
        return raw - backoff if raw > 1500 else raw + backoff
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

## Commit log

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2026-08-08 Retarget spec to measured Ryobi chest geometry
    Measured the supplied STLs instead of trusting the listing. Large drawer
    cavity is 172.6 x 91 x 52 mm, not the ~36 mm assumed - so the SG90 stands
    upright and the lay-flat workaround is dropped.
    - Both cells share one hinge axis, so the hinge becomes a single carrier
    part spanning the full drawer width with a central two-servo spine
    - Bin 69 x 85 x 42, flap 18 g, torque margin now 12x
    - Added drawer-position interlock (flap swings into the bay above if the
    drawer is not fully extended - strips a servo on first try)
    - Added tools/measure_stl.py and project README
    [measure_stl.py]
2026-08-08 Add parametric CAD generator, first printable parts
    cad/toolcell.py builds the parts that drop into the stock Ryobi large
    drawer. Stock chest parts are unmodified. All four outputs watertight.
    Layout changed during modelling: two servos back-to-back in a central
    spine cannot share a hinge axis - their shafts end up 13.5mm apart in
    depth, so the flaps would sit at different heights. Servos moved to the
    outer ends with one idler post in the middle. Carrier also drops from
    32mm to 18mm deep, so bins get deeper.
    Built-in fit checks caught two real errors before export: carrier was
    exactly drawer-width with no clearance, and the two stub axles collided
    by 0.8mm inside the post.
    Final: bins 45.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
    [toolcell.py]
2026-08-08 Fix flap for printing: flat bottom, parts dropped to bed
    Parts were exported in assembly coordinates, so the flaps floated ~28mm
    above the plate in the slicer.
    Worse, the flap's drive arm was centred on the hinge axis, putting 9.5mm
    of it below the plate - printing plate-down would have started the whole
    45x72 first layer in mid-air. Plate now hangs below the axis so the arm,
    axle boss and plate share one flat bottom face. Flap height 22mm -> 7.5mm.
    Added a bed-contact check so this cannot recur silently.
    [toolcell.py]
2026-08-08 Write 3MF directly - trimesh emits an empty build section
    trimesh 5.0's 3MF exporter wrote all 6 objects into <resources> but left
    <build> empty, so slicers opened a plate with nothing placed on it. It
    also discarded node names, leaving geometry_0..5.
    Replaced with a minimal 3MF writer: named objects, one build item each
    with its plate transform. Verified object count == build item count on
    every export.
    [toolcell.py]
2026-08-08 Plate the complete two-level build across 6 plates
    cad/plates.py pulls the stock chest parts straight from the source 3MF
    (unmodified), adds our generated parts, and shelf-packs everything onto
    256mm plates with a fit assertion per plate.
    Two problems it caught: side rails come out of the source running along Y
    at 200mm and overflow the bed the moment anything shares the plate, so
    parts are now auto-rotated landscape. And two large bays stacked to 257mm
    - 1mm over - so each bay now gets its own plate, which is right anyway at
    245g and several hours each.
    Total ~1421 g solid across 6 plates.
    [mf3.py, plates.py]
2026-08-08 Clear stale plate files before regenerating
    An earlier layout left plate_2_bays / plate_3_head_and_drawer /
    plate_4_trim on disk after the plate set was resplit. Two of those had
    failed the bed-fit check, so opening one would have printed something
    that does not fit.
    [plates.py]
2026-08-08 shopkeeper: purpose-built cabinet with rack-and-pinion sliding lids
    Drops the Ryobi host entirely. cad/cabinet.py generates the whole product
    from the mechanism outward: 3 stacking modules, drawer, 2 sliding lids
    with integral racks, printed 24T pinion, panel, feet. 9 parts, all
    watertight, all inside a 256mm bed.
    Sliding replaces the hinged flap. A 66deg flap rose 76mm above the drawer,
    so the drawer had to be at full 105mm extension every time or the servo
    drove into the bay above and stripped. Sliding needs zero vertical
    clearance - drawer position stops mattering, and the SW1 interlock and
    limit stop leave the BOM. The two lids ride at different heights and pass
    over each other, so only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
    [bin_divider.stl, case_base.stl, case_head.stl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]
2026-08-08 shopkeeper MINI: smallest motorised-drawer demonstrator, 120x90x80
    One module, one drawer that drives itself out 33mm on a 14T pinion.
    ~187 g sliced on a single plate - roughly a tenth of the full cabinet.
    Replaces dimension-only assertions with real boolean interference sweeps
    across the whole stroke. They immediately found four faults that the old
    checks passed clean:
    - deck slot was sized for the fin BASE and ignored the teeth, so the fin
    ploughed 2mm into the deck the moment the drawer moved
    - pinion centre distance was measured to the fin base, not the fin pitch
    line, putting it 1.9mm too close to mesh
    - rotating the drawer 180deg to face the mouth also mirrored the fin in X,
    so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
    [case.stl, case_base.stl, case_bay.stl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]
2026-08-08 shopkeeper NANO: two motorised drawers in 92x66x53, ~84 g
    Two drawers SIDE BY SIDE rather than stacked. A vertical SG90 costs 26mm
    of dead height under every deck, so stacking two would have doubled the
    case; side by side they share one mechanism deck.
    cabinet 1365 g -> MINI 187 g -> NANO 84 g, one plate 182x120
    Each drawer keeps its own servo, pinion, fin and GPIO pair - nothing is
    shared between them. Pinion drops to m1.25 x 12T (pitch dia 15) for 23.6mm
    of travel, leaving 57% of the drawer captured at full stroke.
    The boolean sweep caught one more: the OLED mounting posts hung 12mm down
    from the top face, straight through the drawer's path, blocking full
    travel. Shortened to 4mm, whi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
    [case.stl, drawer.stl, pinion.stl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]
2026-08-08 Fix the floating cantilever: rack becomes a separate part
    Bambu flagged the drawer, correctly. The drive rack was moulded onto the
    underside, so printed as modelled the whole 42x62 body floated 8mm in the
    air on a 3mm blade - 4% bed contact. The handle floated 4mm too.
    The rack is now its own part that pegs in through a slot in the drawer
    floor. The drawer prints floor-down at 86% bed contact, and the gear rack
    - the riskiest feature here - becomes replaceable without reprinting a
    drawer.
    Bed contact is now asserted per part (>=25%), which is the check that
    would have caught this before the slicer did:
    case 90% drawer 86% rack 93% pinion 55%
    Two more caught while fixing it:
    - modelli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
    [drawer.stl, plate_nano.3mf, rack.stl]
2026-08-08 Flush drawer fronts with a scalloped cut-in pull
    The protruding handle block was the loudest hobby-print tell on the whole
    object, and it was a 4mm cantilever besides. Fronts are now flush with the
    case and the pull is a 18mm scallop cut into the top-front edge - no extra
    part, nothing to press-fit or lose, and it is self-supporting because the
    void widens as the print rises.
    P['pull'] switches to 'knob' for a revolved press-fit knob instead; that
    part is generated either way and only joins the plate when selected.
    Losing the 7mm handle overhang shortened the drawer 62 -> 55mm, which moved
    the rack, so the pinion is re-centred at PIN_Y 28.5. Contact now sweeps
    7.7 -> 31.3 of a 39mm rack, c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
    [case.stl, drawer.stl, knob.stl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]
2026-08-08 Split the case, fix the floating rack blade, add overhang + tolerance audits
    Bambu was right about all three warnings and the causes were real.
    rack: the blade was built 8mm tall but translated 9.8mm down, so it floated
    1.8mm clear of its own flange - two disconnected solids. 189 -> 4 mm2.
    case: a sealed box was being asked to print its own 88x62 ceiling, and the
    deck underside was another 3981 mm2 of mid-air. Split into case_lower (open
    top), a flat deck plate on side+rear ledges, and case_upper printed top-face
    down. 9633 -> 766 mm2, all of it 3mm ledge overhang that bridges fine.
    Two more the interference sweep caught while splitting: the deck ledge ran
    a front rail straight through bo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
    [case.stl, case_lower.stl, case_upper.stl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]
2026-08-08 Drive the pinion through the servo horn, not the spline
    The tolerance audit called the pinion bore at +0.175/side where a press fit
    is needed. Widening tolerance was never the answer: an SG90 spline is 20
    teeth on a 4.8 mm diameter, a 0.75 mm pitch, and a 0.4 mm nozzle cannot
    resolve that. Any printed bore reams itself round and slips under load -
    and this joint carries the entire drive.
    The pinion now bolts to the servo's own double-arm horn: a boss recess, a
    keying slot for the arms, two M2 holes at r=6 matching the horn, and a
    4.6 mm bore so the servo's M2.5 centre screw is still reachable with a
    driver after assembly. Trim the horn arms to 8 mm a side.
    Bed-contact check now exempts par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
    [pinion.stl, plate_nano.3mf]
2026-08-08 Fix the gear teeth the bug hunt confirmed, plus per-object colours
    CONFIRMED BLOCKER from the hunt: rack tooth half-thickness was measured at
    the TIP, but the pinion measures at the pitch line. So the rack teeth came
    out ~0.9mm too fat - negative backlash, a pair that jams rather than turns.
    The same error made the root troughs 0.25mm wide. A 0.4 nozzle cannot open
    that, so the slicer fills it and the rack prints as a solid bar with a
    scalloped edge. Trough is now 1.46mm.
    Rack is now pitch-line referenced like the pinion, and the pressure angle
    drops 20 -> 14.5 deg to keep the tips printable at 1.02mm.
    Tolerance audit gained tip-thickness and trough-width checks so a gear that
    cannot be e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
    [pinion.stl, plate_nano.3mf, rack.stl]
2026-08-08 One colour per plate, thinner perforated floor
    Per-object colours were wrong for a single-nozzle P2S: every swap costs a
    filament change and a purge tower. Split into two single-colour plates
    instead - swap the spool between prints, zero purge.
    plate_1_white 195 x 78 53 g case_lower, case_upper
    plate_2_yellow 213 x 97 46 g deck, 2 drawers, 2 racks, 2 pinions
    Floor drops 2.0 -> 1.4mm and is perforated on a 13mm grid, skipping the
    servo cradles and ESP32 posts. It carries nothing else, and every gram
    there is print time. case_lower 44 -> 30 g.
    [case_lower.stl, plate_1_white.3mf, plate_2_yellow.3mf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]
2026-08-08 Fix all five remaining confirmed findings
    BLOCKER - the drive stack did not fit vertically. An SG90's shaft top is
    29mm above its base and the pinion rides on the horn above that, so the
    gear band sat above the deck while the rack it drives hangs below it. They
    could never mesh. Deck raised 25.5 -> 33, case 53 -> 60mm tall. Gear band
    28.4-33.4 now sits inside the fin's 27.5-35.5.
    - shell cavity ran out through the back face: there was no rear wall at all,
    so the DC jack, service window and ESP32 fixings cut through nothing
    - mullion between the two drawer mouths was 0.80mm; mid_gap 2 -> 6 makes it
    4.8mm of actual material
    - servo cradle was narrower than the 27.8mm tab-screw pitch, so a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
    [case_lower.stl, case_upper.stl, deck.stl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]
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2026-08-08 One file, two plates: shopkeeper_nano.3mf
    Single-nozzle machine, so the colour boundary has to be a plate boundary,
    never a swap mid-print. This writes a Bambu multi-plate project:
    plate 1 White case_lower, case_upper
    plate 2 Yellow deck, 2 drawers, 2 racks, 2 pinions
    mf3.write_3mf_plates emits Metadata/model_settings.config with a <plate>
    per group and a model_instance per object, and offsets each plate by 266mm
    in X so objects land on their own bed in the global scene.
    Verified in the archive: 9 objects, 9 build items, 9 model_instances, two
    named plates, plate-2 transforms all beyond x=266.
    plate_1_white.3mf and plate_2_yellow.3mf stay as single-plate fallbacks.
    Co-Authored-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
    [plate_1_white.3mf, plate_2_yellow.3mf, plate_ALL.3mf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]
2026-08-08 Revert the multi-plate file: Bambu overlapped it
    Tried a Bambu multi-plate project with plate 2 offset 266mm in X. Bambu did
    not bin the objects into a second plate - everything landed in one scene and
    overlapped. The archive was well formed (2 named plates, 9 model_instances)
    but the layout convention is evidently not what I assumed.
    Back to two separate single-colour files. Open one, slice, swap the spool,
    open the other.
    [plate_1_white.3mf, plate_2_yellow.3mf, shopkeeper_nano.3mf]
2026-08-08 Cut case_lower floating regions 917 -> 533 mm2
    Bambu flagged case_lower and every cause was real:
    - the servo cradles started at z=2.0 while the floor top is 1.4, so both
    cradles floated 0.6mm clear of the floor they are supposed to stand on
    - rectangular vent slots leave a flat roof; round holes are self-supporting
    - the rear service window was one 56mm opening whose top edge is a 56mm
    bridge; now three 15mm windows with pillars between them
    - the deck ledge was a 3mm shelf off the wall with nothing under it, and it
    was the single biggest region; 1.5mm still carries a 2.5mm plate
    case_upper gains a 45 deg relief above each drawer mouth, since it prints
    flipped and that wall would ot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
    [case_lower.stl, case_upper.stl, plate_1_white.3mf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]
2026-08-08 Fix the detached mullion in case_upper
    You spotted a small divider floating and it was exactly that: a 4.8 x 2.0 x
    17.8mm sliver of the wall between the two drawer mouths, a separate body
    with nothing holding it on.
    Cause was a double translation. blk() already places a box at x0..x1, but
    the 45 deg mouth relief was then translated AGAIN by (x0+x1)/2, so each
    wedge landed ~23mm to the right of where it belonged and cut clean through
    the mullion instead of the wall above the mouth.
    Added a permanent check: every part must be exactly one body. That would
    have caught this, and it would have caught the detached rack blade earlier
    too - both were watertight, so watertightness alone never proves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
    [case_upper.stl, plate_1_white.3mf, plate_2_yellow.3mf]
2026-08-08 Preflight: assemble the real meshes and clear them to print
    cad/preflight.py builds every shipped STL in its true pose, adds a solid
    SG90 proxy, and boolean-intersects every pair. It reads meshes, not source
    variables - the source has been right and the mesh wrong before.
    It found one real collision on the first run: the pinion's top sat 0.4mm
    INSIDE the deck's underside. The gear would have ground against the plate
    it drives through. Deck raised 33 -> 34.5, case 60 -> 62mm, giving 1.1mm
    clearance and still 4.4mm of pinion/rack tooth overlap.
    Also fixed the check itself: it measured the rack's tooth tip as max-x over
    all vertices, which hits the FLANGE at x=8 rather than the teeth at 5.81,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
    [case_lower.stl, case_upper.stl, plate_1_white.3mf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]
2026-08-08 Drop the basematerials group: Bambu demanded a filament mapping
    Declaring basematerials made Bambu treat the file as multi-material and
    refuse to slice until filaments were mapped. On a single-nozzle machine
    there is nothing to map, so it was an unclearable error.
    The colour was never information the file needed to carry. Each plate is one
    colour because of which spool is loaded. Both plates are now plain
    single-material 3MFs: no basematerials, no pid, no pindex.
    [plate_1_white.3mf, plate_2_yellow.3mf]
2026-08-08 Make the pinion actually fit an SG90 horn
    Checked against real horn dimensions, three things were wrong:
    - arm is 7.0mm wide at the boss but the slot was 5.8: it would not seat
    - arms are 17.5mm each side against an 8.75mm gear radius
    - screw holes fixed at r=6 only suit horns with a hole exactly there
    Slot widened to 7.6 x 16 x 2.1 to clear the arm's WIDEST point. Screws
    dropped entirely: at a 15mm pitch diameter no screw clears the tooth roots
    at r 5.94. The slot is the drive - a keyed joint bearing ~0.7 MPa against
    PETG's ~50.
    Assembly: screw the horn to the servo with its own M2.5, trim the arms to
    8mm a side, press the pinion on, one drop of glue. The 4.6mm bore still
    reaches the M2.5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
    [pinion.stl, plate_1_white.3mf, plate_2_yellow.3mf]
2026-08-08 Option A: 16T pinion and a full-length rack, travel 23.6 -> 31.4mm
    Drawer extraction 43% -> 57% with no change in case size.
    12T -> 16T pitch dia 15 -> 20, travel 23.6 -> 31.4mm
    rack DR_D-16 -> -6 39 -> 49mm, so the longer stroke stays meshed
    FIN_X 0.30 -> 0.20 the bigger pinion's servo cradle was going to
    overhang the right-hand case wall
    PIN_Y 28.5 -> 17.6 re-centres contact: 8.8 -> 40.2 of a 49mm rack
    Two things this shook loose:
    - moving PIN_Y put both servos where the ESP32 posts were. The board is
    63mm long in a 66mm-deep case, so it cannot lie along Y beside them; it
    now runs along X at the rear.
    - the retention check was wrong, not the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
    [case_lower.stl, deck.stl, drawer.stl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]
2026-08-08 Add an ESP32 cradle and breadboard mounts inside the case
    ESP32-S3 (63 x 25.5) now drops into slide-in rails with a retaining lip
    rather than sitting on four bare posts - no screws, and the USB-C end faces
    the rear window so it can be reflashed with the case shut. An end stop at
    the front stops it sliding forward.
    Four pillars 12mm tall carry a half-size breadboard above the cradle for the
    servo wiring; the board's adhesive back sticks to the pillar tops. Pillars
    that would land past the rear wall are skipped, and the lightening-hole
    keep-out grew to 40mm so the floor stays solid under all of it.
    Verified: case_lower still one solid body, 100% bed contact, and preflight
    still CLEARED - the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
    [case_lower.stl, plate_1_white.3mf, plate_2_yellow.3mf]
2026-08-08 Assign every object to filament 1 so Bambu can slice
    Removing basematerials stopped the multi-material error but left the
    filament unstated, and Bambu then asks for a mapping it has nothing to map.
    Both plates now ship Metadata/model_settings.config assigning extruder 1 to
    every object and every part. Still no basematerials, still single-filament -
    the colour comes from whichever spool is loaded.
    plate_1_white 2 objects, 4 extruder-1 assignments
    plate_2_yellow 7 objects, 14 extruder-1 assignments
    [plate_1_white.3mf, plate_2_yellow.3mf]
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2026-08-08 Fix the case: overhangs 765 -> ~200 mm2, cradle sized for a WROOM-32D
    Deck ledge is now a 45 deg gusset instead of a square shelf - a flat shelf
    underside is unsupported, a 45 deg one prints itself. The ESP cradle's
    undercut retaining lip went too: it was 255 mm2 on its own, and a plain
    channel plus a dab of glue is all a demo needs.
    Also corrected the analyser. 45 deg is the accepted self-supporting limit and
    has normal_z = -0.7071, so a -0.70 threshold flagged every deliberate
    chamfer as a defect. -0.75 lets true 45 deg pass and still catches flatter.
    Board is an ESP32-WROOM-32D DevKit, not an S3: 54.4 x 27.9, and 27.9 will
    not go into the 25.5 channel I had. These DevKitC boards have no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
    [case_lower.stl, plate_1_white.3mf, plate_1_white.stl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]
2026-08-08 Show the ESP and servo mounts on localhost; re-audit tolerances
    cad/mounts_page.py cuts a plan section through the real case_lower mesh at
    z=6 and overlays the two SG90 cradles and the ESP32-WROOM-32D channel, with
    the fits called out. 3D viewer regenerated off the current meshes.
    Tolerance audit updated for 16T, mid_gap 6 and the electronics mounts:
    ESP32-WROOM-32D in channel +0.35/side ok
    servo body in cradle +0.35/side ok
    cradle spans tab pitch 36.2 vs 32.2 ok
    0 tight, 4 loose
    [mounts_page.py, tolerances.py]
2026-08-08 Case grows 66 -> 94 deep to take the breadboarded ESP32-S3
    The board in the photo is an ESP32-S3 DevKit (RGB LED, RST/BOOT, two USB-C),
    not a WROOM-32D - my earlier change was wrong and I should have asked for a
    photo before making it.
    More to the point it is plugged into two breadboard strips and stays that
    way, because no soldering. Measured assembly 81.5 long x ~52 across. That
    does not fit behind the servos in a 66mm-deep case - 36mm available against
    50 needed.
    So the case grows backwards, not upwards: the breadboard sits in the mech
    bay behind the servos, under the deck, where there is 34.5mm of height doing
    nothing. Corner walls locate it; its own adhesive back holds it.
    Drawer dep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
    [case_lower.stl, case_upper.stl, deck.stl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]
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2026-08-08 Alignment pins between the case halves - no magnets needed
    The halves only located on the deck ledge, which is loose. Four printed pins
    on case_lower's rim now enter sockets in case_upper.
    pin 1.80 dia x 4.0 tall
    bore 2.15 dia x 4.5 deep -> 0.175 per side, slip fit, pulls back apart
    They sit on the wall CENTRELINE, 1.0 from the outer face, and the deck starts
    at 2.3 - so they clear it without notching the deck anywhere. They locate
    only; the ledge and walls still carry the load.
    Verified by assembling both halves and intersecting: 0.00 mm3.
    [case_lower.stl, case_upper.stl, plate_1_white.3mf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]
2026-08-08 Alignment pins on solid shoulders, not thin walls
    You were right that mid-wall pins in 2mm of wall would snap. Moved to
    shoulders with 6mm gusset pads.
    Not four corners though: the two FRONT corners sit inside the drawers'
    travel and a pad there is struck at 8mm of pull. So both REAR corners plus
    the front MULLION, which is 6mm of solid material between the drawer
    mouths. Three well-spread points beat four with one in the way.
    pin 3.0 dia x 4.0 tall on a 6x6 pad
    bore 3.35 dia x 4.6 deep -> 0.175 per side
    Two knock-ons the checks caught: the rear corner notches ate the strip
    holding the deck's three sections together (fin slots now stop 8mm short of
    the rear, not 3), and the notch o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
    [case_lower.stl, case_upper.stl, deck.stl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]
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2026-08-08 Deboss the Ommi Forge mark into the case top
    cad/logo.py traces the mark from the bitmap: pixel runs -> shapely boxes ->
    one unary_union -> simplify. 7 shapes, 1011 vertices. Union in 2D and extrude
    once, rather than booleaning hundreds of prisms in 3D.
    11mm tall, debossed 0.7 into the top face in the front border ahead of the
    keypad. case_upper prints top-face-down so the mark's edges form against the
    bed. Black on white via a paint pen - a colour change is not worth a purge
    tower on a single nozzle.
    Two process failures worth recording: my sed-style patches printed 'patched'
    unconditionally, so a replace whose anchor no longer existed reported success
    and I believed it twice. And extrude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
    [case_upper.stl, plate_1_white.3mf, plate_1_white.stl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]
2026-08-08 Logo in white PLA: deboss 1.1 deep so it reads as shadow
    No second colour - the mark is the same white PLA as the case. White on white
    reads only as shadow, so it is cut 1.1 deep rather than 0.7, which leaves
    0.9 mm of the 2.0 mm top plate under it.
    Deepening it exposed a bug: I moved the pocket down but left the cutting prism
    0.9 tall, so it stopped 0.2 below the surface and left a skin over the mark.
    case_upper split into 8 bodies - one shell and seven floating caps. The prism
    now extrudes 1.6 and breaks the surface.
    The single-body check caught it immediately, which is the third time that
    check has paid for itself.
    [case_upper.stl, plate_1_white.3mf, plate_1_white.stl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]
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

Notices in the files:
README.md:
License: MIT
